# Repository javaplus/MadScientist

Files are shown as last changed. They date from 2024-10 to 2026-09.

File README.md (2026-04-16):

# Mad Scientist Lab V2.0 Sharks on Mars!

Fun learning with Electronics and Raspberry Pi Pico

This is the V2.0 of the Mad Scientist lab.  The original shark with laser game and more gentle introduction to electronics and the Pico can be found here: https://github.com/javaplus/PicoProjects

## The Grab

 Using Raspberry Pi Pico microcontrollers, Python, electric motors, 3D printed parts, and your ingenuity, you will construct a rover ready to conquer Mars! This vehicle will be capable of traversing rough surfaces like those of the red planet and will be programmable to handle out of this world challenges. Remember those mechanical sharks with freakin' lasers on their heads? Well HONEY WE BLEW UP THE SHARKS and will be using those shark parts to transform these rovers into the ULTIMATE MAD SCIENTIST vehicles to fend off any threats you may encounter in this extra-planetary conquest.
Once you've built your functioning rover in our lab, if you choose, you will have the opportunity to battle test your vehicle against other rovers to see whose design reigns supreme! Join us in this epic quest and learn to meld software and hardware together to accomplish our goal of bringing Sharks to Mars!

## Description

This is a tutorial for building a Shark Rover.  A Shark Rover is just like it sounds... a mix between a shark and a Mars-like rover.  

Nearly all the plastic parts are 3D printed and the brain is a Raspberry Pi Pico.  You will assemble the plastic bits and install the Pico, the motors, wires, and other electronics to make a functioning autonomous rover.
We will use Python as the programming language for the Pico microcontroller, but all code will be provided.

# Prepare Pico

To prepare the Pico, you need to flash it to support MicroPython.
Here are the instructions to [flash the Pico for MicroPython](/lessons/firmware.md).

# Getting Started

If you want to jump straight into building the Shark Rover, jump to the [Assembly](#Assembly) section.  If you want to take a slower approach and learn about each component, check out our [Lessons](#Lessons).

### 🚀 One-Day Event?

If you're building a rover for a one-day event with mixed/pre-assembled kits, start here: [Hackathon Build Notes](UA_hack_special_notes.md) — quick, scannable instructions designed for event participants.

# Lessons

The links in this section are to labs which walk you through working with the various components that will ultimately make up your rover. These labs will give you a better understanding of the individual parts and code that go into making the rover work.  However, these lessons do not actually get into building the rover, but are just for learning how the components work.  They are hands-on labs that actually have you working with the electronics and code, but do not include assembly of the rover.  The assembly is in its own section.  So, if you don't care to learn how the individual components work and want to skip straight to building the rover, then skip this section and go straight to [Assembly](#assembly) below.

[Blink Demo](/lessons/blink.md)  
[Simple LED](/lessons/Led.md)  
[LED PWM](/lessons/led_pwm.md)  
[RGB LED](/lessons/RGBled.md)  
[Working with Electric Motors](/lessons/SimpleMotor.md)  
[Motor Controller](/lessons/MotorController.md)  

# Assembly

[Pico Plate](/lessons/assembly/plate.md)  
[Chassis Motors](/lessons/assembly/chassis.md)  
[Wheels and Tracks](/lessons/assembly/wheels.md)  
[Power Components](/lessons/assembly/power.md)  
[Pico and Chassis Together](/lessons/assembly/plate_chassis.md)  
[Tail Tip/Photoresistor](/lessons/assembly/tail.md)  
[Tail Connection](/lessons/assembly/tail_chassis.md)  
[Head, RGB Leds, and adding the cap!](/lessons/assembly/head.md)  

# Install the Code

[Install the Code](/lessons/assembly/code_install.md)

# Customize the Code

[Custom Game Modes](/lessons/game_mode_coding.md)

# BlueTooth Remote

[Mad Scientist App](https://github.com/javaplus/mad_scientist_app)

---

## 🦈 Wiring Reference

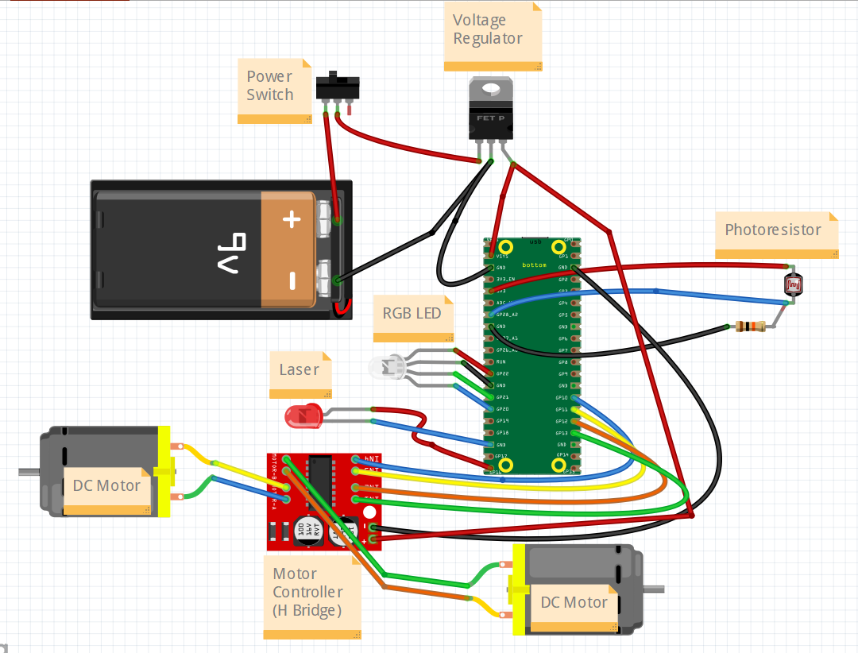
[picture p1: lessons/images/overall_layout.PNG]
Overall Wiring Diagram


**Use the image above for the main layout!**

> ⚠️ **One Addition (The Buzzer)**  
> The diagram is missing the buzzer, which we added later.  
> **Signal:** Connect to `GP15` (Right next to the Laser on `GP16`)  
> **Ground:** Connect to any `GND`

**Summary of Pins:**
- **Motors:** `GP10`, `GP11`, `GP12`, `GP13`
- **Buzzer:** `GP15`
- **Laser:** `GP16`
- **RGB Eyes:** `GP20` (Blue), `GP21` (Green), `GP22` (Red)

See [head wiring details](/lessons/assembly/rgb.md) for head wiring details.

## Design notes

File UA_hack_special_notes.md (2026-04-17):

# 🧪 Mad Scientist — Event Build Notes

This guide is designed to help you get your kit running quickly and safely. Because these kits are shared and reused, the most important rule is: **Build smart, not permanent.**

---

## 🛑 The Golden Rules (Read This First!)
To ensure these kits work for the next person, follow these rules strictly:
* **No Permanent Changes:** Never cut wires, solder, glue, drill, or sand any parts. 
* **Hands Off the Repairs:** If a part looks broken, frayed, or won't fit, **stop and ask a facilitator.** Do not attempt your own repairs.
* **The "Reversible" Rule:** If you can’t undo what you just did in 10 seconds, you’re doing it wrong.
---

## 🔌 Wiring & Connections
The wiring diagram is the final authority. If a tutorial says one thing but the diagram says another, **follow the diagram.**

* **Wiring Diagram:** [View Layout Image](lessons/images/overall_layout.PNG)
* **Pin Reference:** See the "Wiring Reference" in the [README.md](README.md#-wiring-reference).
* **Pro Tip:** If a connector doesn't slide in easily, check the alignment. **Never force a plug.**

---

## 🛠 Troubleshooting (Quick Fixes)

| Issue | Check This First |
| :--- | :--- |
| **No Power** | Check battery orientation and the physical power switch. |
| **Motor Swapped** | If the bot moves backward, ask a facilitator to run a "Motor Direction Test." |
| **Wrong LED Colors** | Your RGB harness might be upside down. Check the [RGB Guide](lessons/assembly/rgb.md). |
| **Smoke or Smell** | **Switch off power immediately** and notify a facilitator. |

---

## 🚀 Final Assembly
Once your electronics are tested and working:
1.  **Mount the Head:** Align the head unit with the chassis. It should slide or snap into place without force.
2.  **Secure the Cap:** Install the final top piece (the "Cap"). If unsure which piece this is, ask a facilitator.
3.  **Safety Check:** Ensure no wires are pinched or dragging on the wheels.

---

## 📚 Essential Links
* [Master Wiring Diagram](lessons/images/overall_layout.PNG)
* [Firmware & Code Install](lessons/assembly/code_install.md)
* [Full Parts List](resources/PartsList.md)

> **⚠️ LASER SAFETY:** This kit contains a Laser. Never look directly into the beam or point it at anyone’s eyes. (Facilitator will confirm safety protocol before use).

## Assemble Your Shark!

Go To Assembly Instructions:
[Assembly](README.md#assembly)

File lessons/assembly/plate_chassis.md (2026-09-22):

# Add Plate on Chassis

### Parts
- Pico plate (with Pico and motor controller)
- Chassis

In this step, we will take the Pico plate with the Pico and motor controller and attach it to the chassis.  

### Connecting the Motors

Before we can put the plate down on the chassis, we need to connect the motors to the motor controllers pins that stick out below the plate.  Position the chassis so that the hitch is facing towards you which means the power switch also is closest to you.  Then position the pico plate with the motor controller at the opposite side of the chassis.
See below picture for proper orientation.   

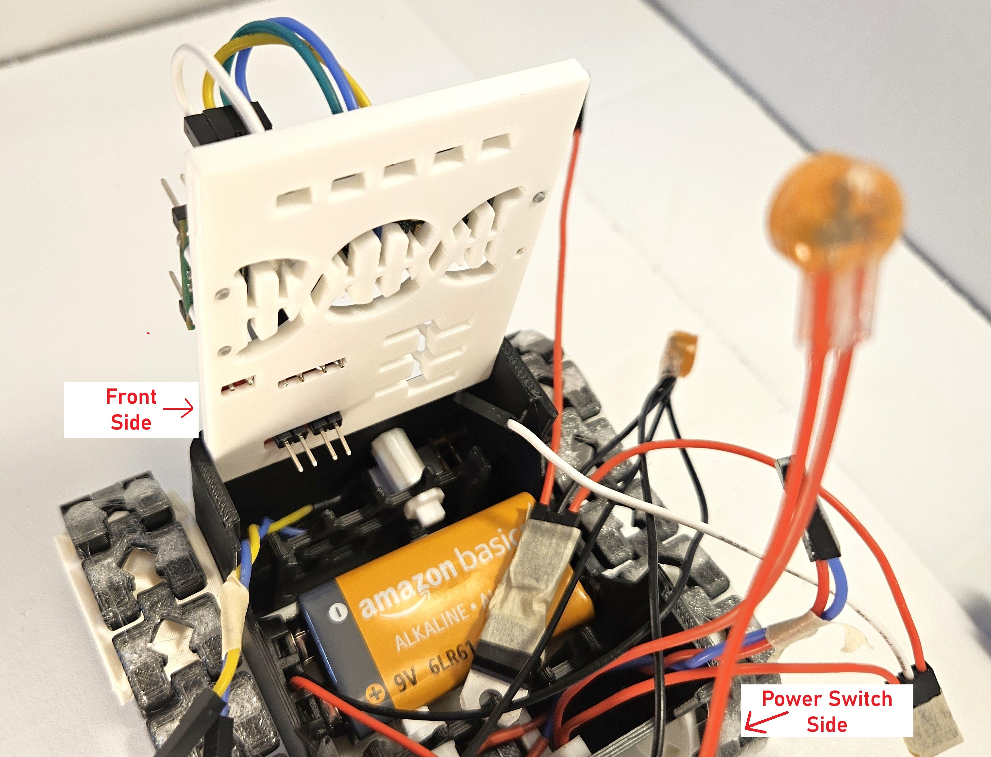
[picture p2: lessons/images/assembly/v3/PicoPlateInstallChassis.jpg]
Pico Plate bottom view


Now you will connect the motor wires to the motor controller pins that stick down through the pico plate. Connect the front motor to the `motor A` pins on the motor controller. The ``motor A`` pins are the first two pins on the left in the picture above. 

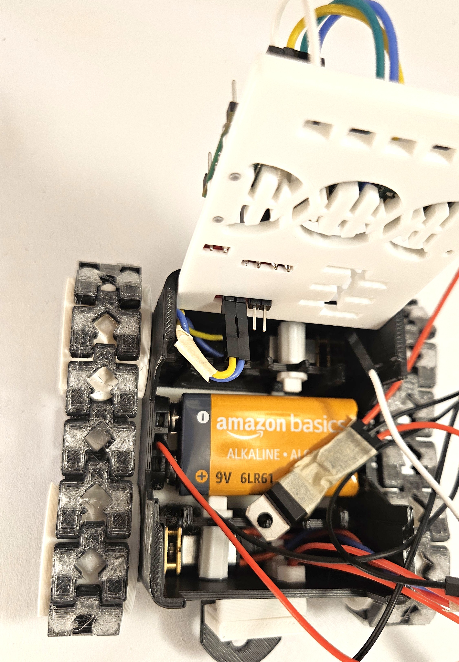
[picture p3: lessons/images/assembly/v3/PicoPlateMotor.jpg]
Pico Plate Motor A pins connected


 Connect the rear motor to the `motor B` pins.  Run the wires for the rear motor over the battery. You don't have to worry about the color of the wire and which pin it goes to.  As long as the front motor wires are connected to the `motor A` pins and the rear motor is connected to `motor B` pins, then which wire connects to which pin doesn't matter.   The reason it doesn't matter is because the motor controller can send power in both directions to a motor and therefore we can control in the code which way to send the power to get the motors to spin in the direction we want.

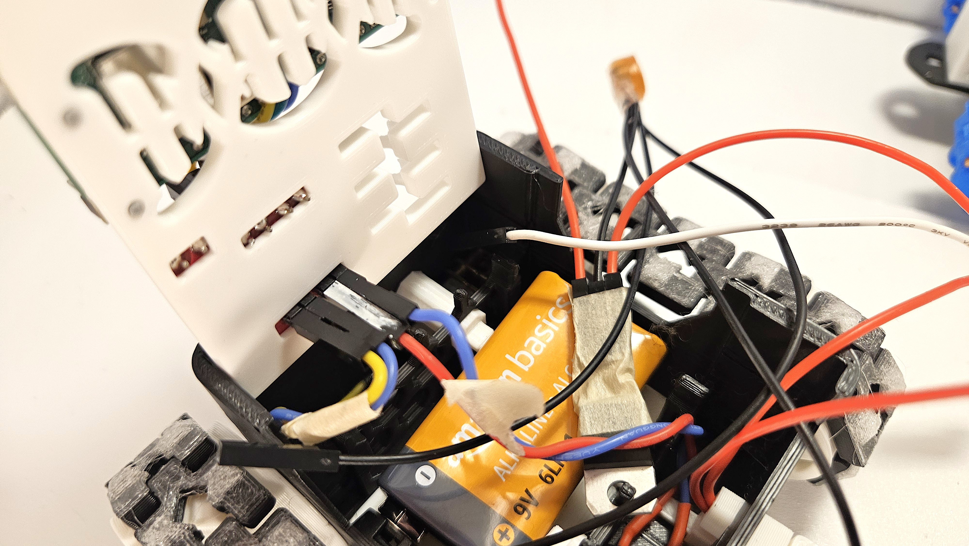
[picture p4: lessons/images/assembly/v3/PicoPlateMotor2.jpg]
Pico Plate Motor B pins connected


### Running the Power Wires

Now we need to route all the unconnected wires from the power up through the Pico Plate.  So, you should have 2 black ground wires and 2 positive wires(one red and one white).  Be sure to know which wire is coming straight from the 3 way connector and which is coming from the Voltage Regulator.  The one coming from the 3 way connector is carrying 9volts and could damage the Pico if we accidentally plugged it in there.  In our picture the white wire is carrying the 9volts and will go to the motor controller eventually.  For now, just run all 4 wires through the slots in the bottom right of the Pico Plate. Their position in the slots doesn't matter, just have them all poke through to the other side of the Pico plate.

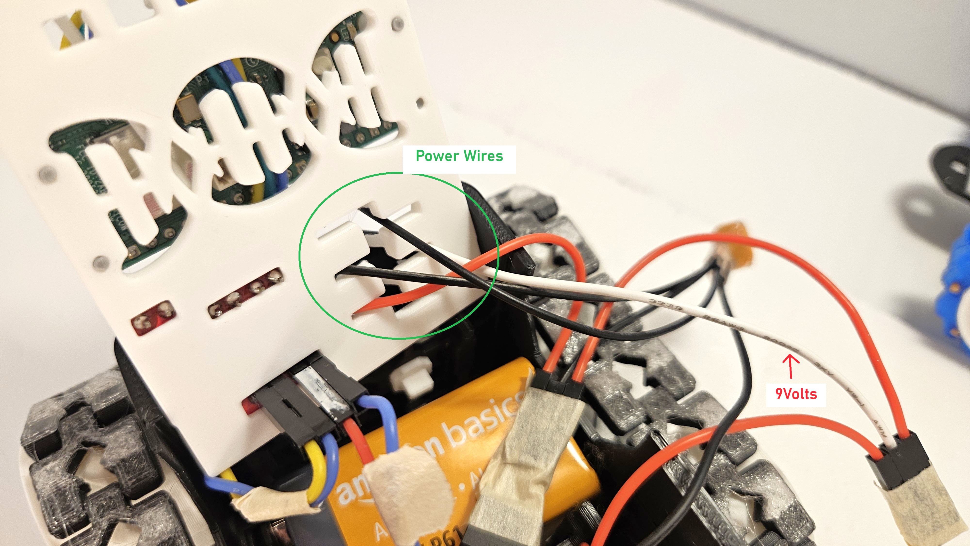
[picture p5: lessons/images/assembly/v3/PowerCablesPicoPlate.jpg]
Power Cables Through Pico Plate


With the 4 power wires through the Pico plate, you can set plate on top of the chassis. Don't worry about snapping the Pico Plate in place. At this point, just let the Pico Plate rest on top of the chassis.

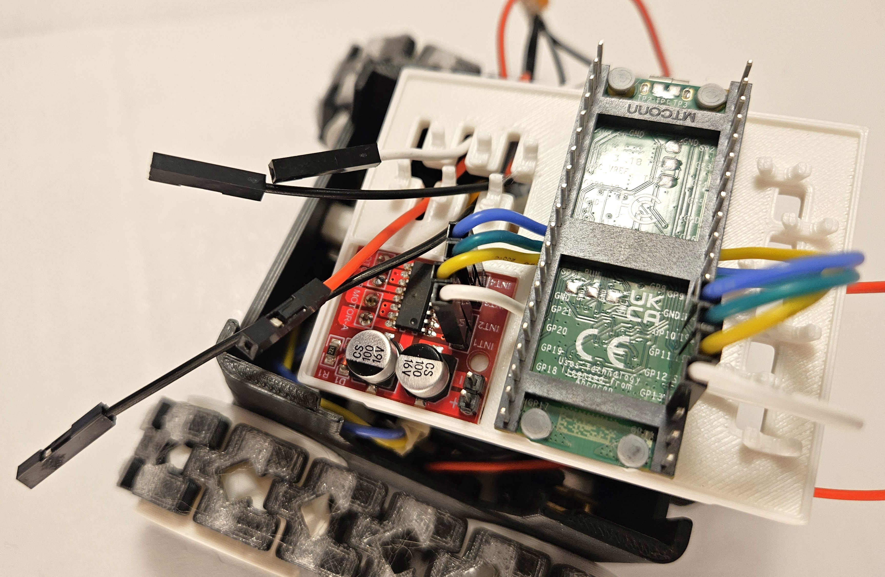
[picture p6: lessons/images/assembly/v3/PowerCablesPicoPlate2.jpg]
Power Cables Through Pico Plate Top View


Now we will try to push the Pico Plate into is final recessed position on the chassis.  To do this, start by positioning the Pico Plate inside the top of the chassis.

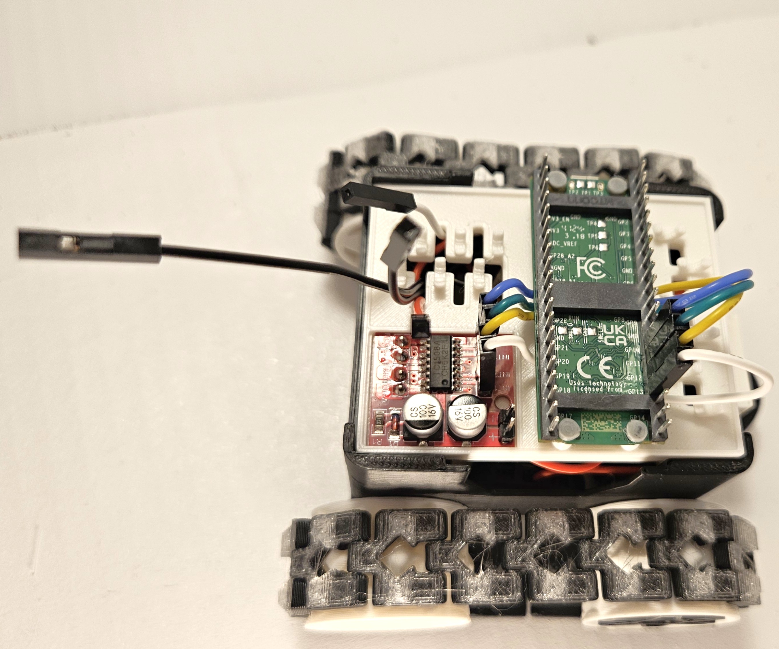
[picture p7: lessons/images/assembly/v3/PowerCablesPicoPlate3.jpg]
Pico Plate On Chassis


Your goal now is to carefully push the plate down onto the chassis. Make sure that the wires aren't disconnected or pinched between the plate and chassis. You may need to pull up on the ends of the power wires to bring slack up above the Pico Plate.  Continue to gently push the Pico plate down onto the chassis while keeping the wires from getting pinched. The plate should sit flush with the cutout in the front and rear of the chassis.

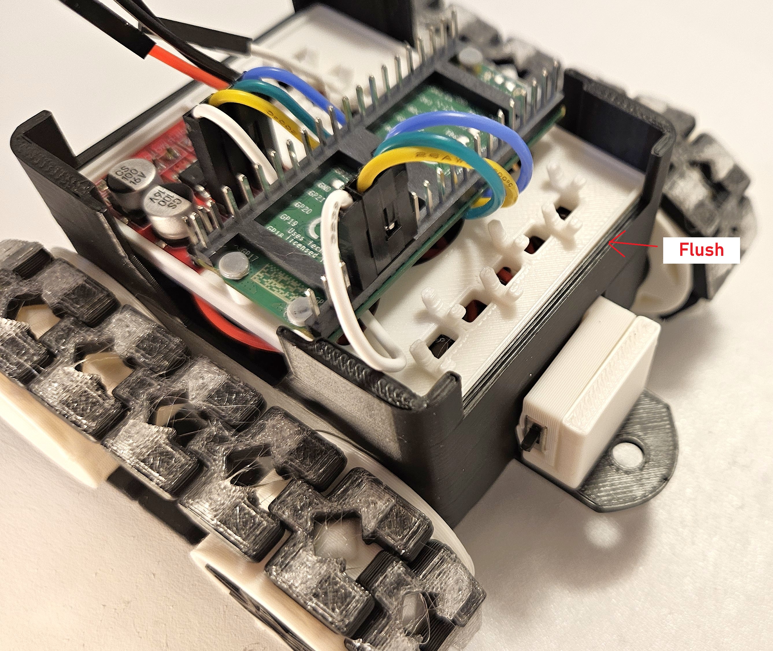
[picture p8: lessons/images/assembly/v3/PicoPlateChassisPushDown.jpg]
Pico Plate on Chassis Flush back
  

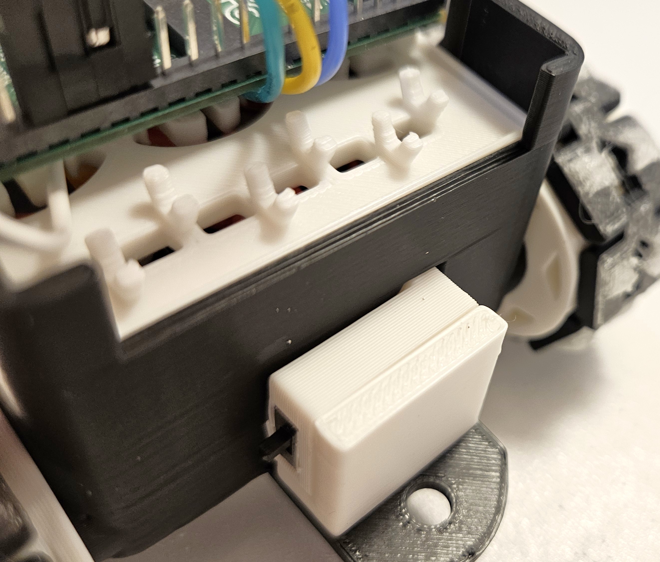
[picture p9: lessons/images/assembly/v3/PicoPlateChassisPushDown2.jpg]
Pico Plate on Chassis Flush back 2
  

Ensure the Pico is pushed down and flush with the front and back edges of the chassis.  You may have to reposition the wires underneath a few times and tuck them down in crevices by the motors to get it to fit flush.

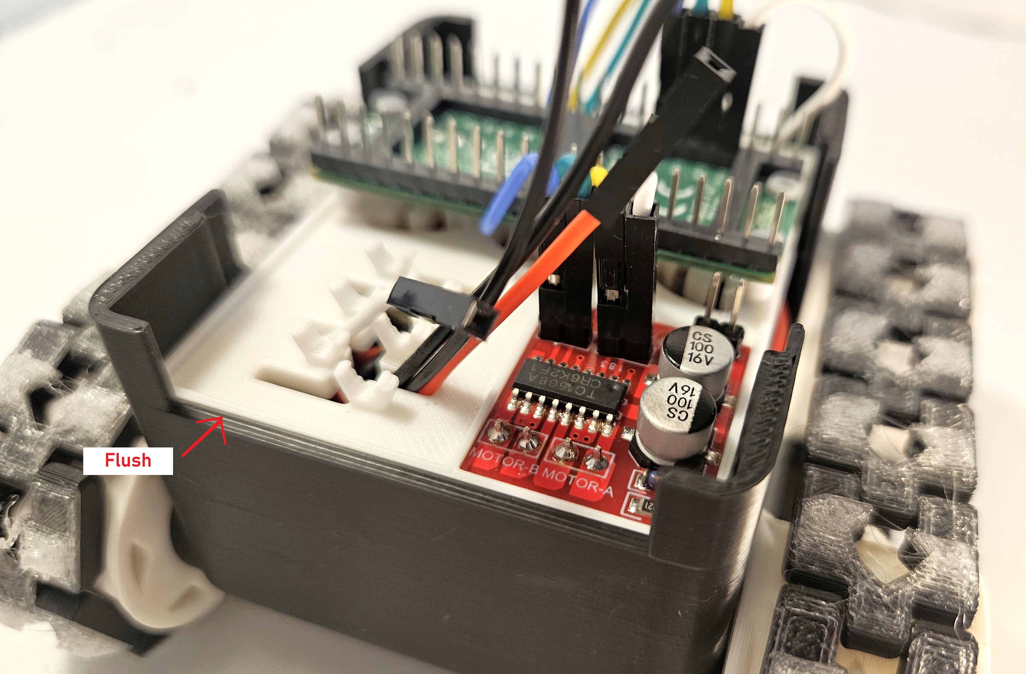
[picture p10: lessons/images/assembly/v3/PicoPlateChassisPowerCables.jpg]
Pico Plate on Chassis Flush Front


Now it's time to connect the power cables from the voltage regulator.  Connect either of the ground (black) wires to the (-) pin on the motor controller and connect the 9Volt positive wire (should be white) to the (+) pin on the motor controller.  The negative/ground pin is the one 

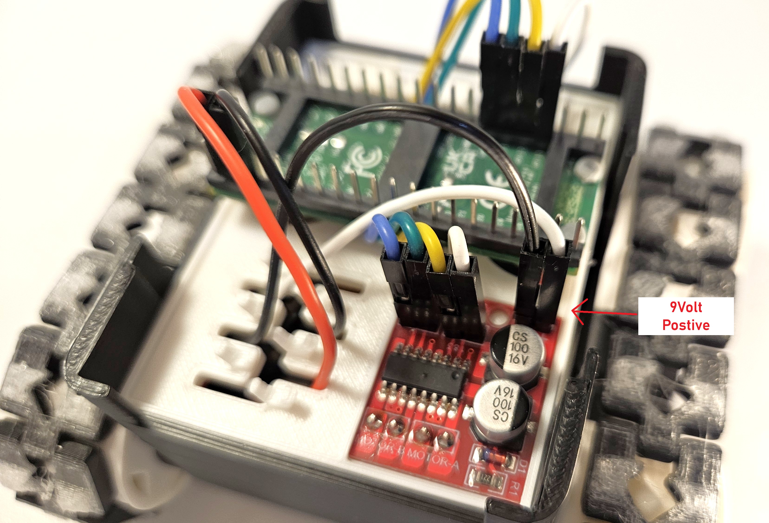
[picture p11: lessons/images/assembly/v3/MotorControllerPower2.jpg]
Motor Controller Power Wires


Now we need to connect the power to the Pico. 
Take the positive wire coming from the voltage regulator that should carry our 5 volts the Pico's VSYS pin (left side, second down from the ).  The other ground wire (black) connects right beside the VSYS pin into a GND(ground) pin on the Pico.  See the picture below and be sure to notice there is one single empty pin to the left of the positive wire and your red wire is connected to the second pin from the left in the picture below. There is always ground 3 pins in from any side on the Pico.

Here's a pinout diagram if you want to use it instead of the pictures:  
<details><summary> Click here to hide/show Pico Pin Out.</summary> 
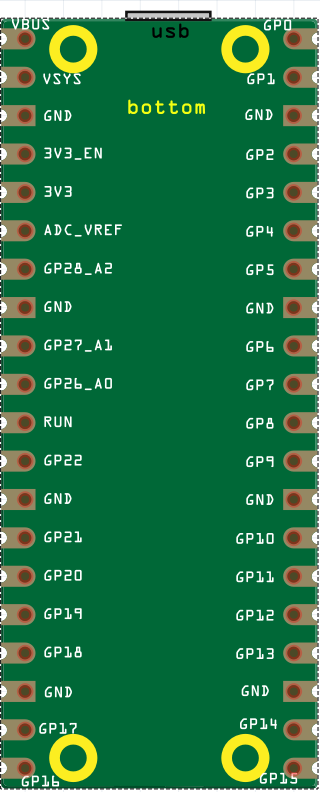
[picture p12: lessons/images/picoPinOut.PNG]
 
</details>

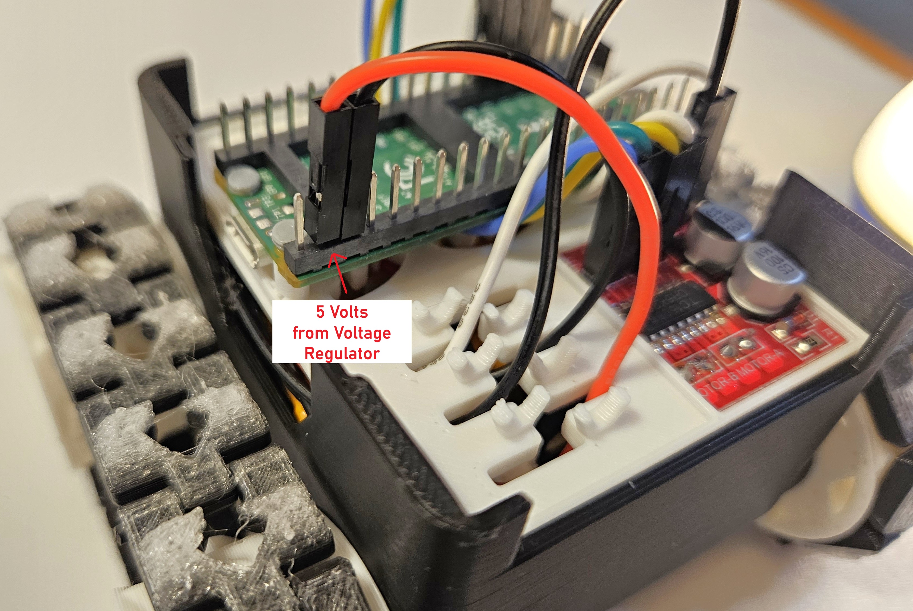
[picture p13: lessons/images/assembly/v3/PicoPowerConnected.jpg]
Pico Power Wires


The ground/black wire goes to a ground pin on the Pico.  We recommend the ground pin right next to the VSYS.  That is 3 pins down from the top left in the picture.

### Test the Motors

TODO: Add instructions to test the motors via a simple program on they load on the Pico.  Similar to the motor controller lesson. Preferably the same code.

### Install Rover Code

Congratulations! You are super close to having a mobile rover!

Actually, if you already have your wheels and tracks installed, you may want to go ahead and install the code and test out what you have built.

You should be able to install the code and use the mobile app to test the basic drivability of your rover.

- [Install Shark Code](/lessons/assembly/code_install.md)  
- [Mobile app](https://github.com/javaplus/mad_scientist_app/blob/main/README.md)

[back](https://github.com/javaplus/MadScientist/blob/main/lessons/assembly/power.md)                

[next](https://github.com/javaplus/MadScientist/blob/main/lessons/assembly/tail.md)

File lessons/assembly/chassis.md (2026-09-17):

# Chassis Assembly

### Parts

- Chassis
- 2 motors
- 2 hex plugs

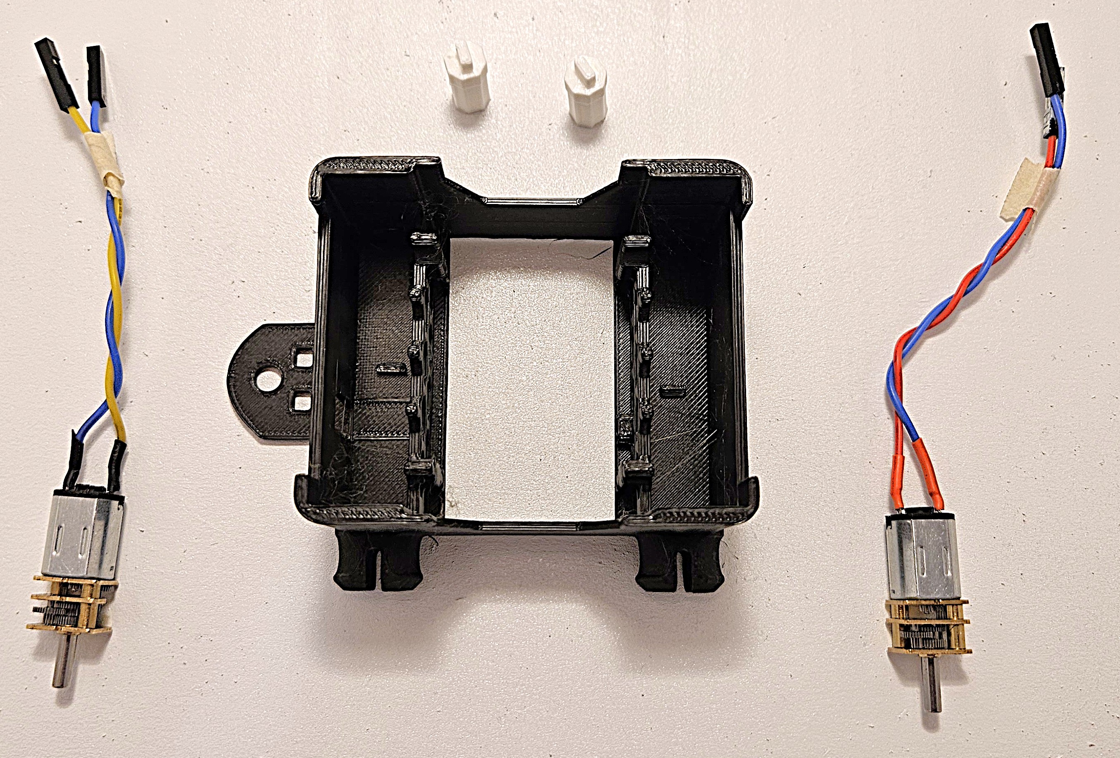
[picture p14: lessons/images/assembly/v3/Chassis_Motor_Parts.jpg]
Chassis and Motors Not Installed


### Remove tabs

There may be two tabs attached to the inside bottom of your chassis.  If they are on your chassis, remove them.  They should easily bend and snap off with little effort. They are not needed. 

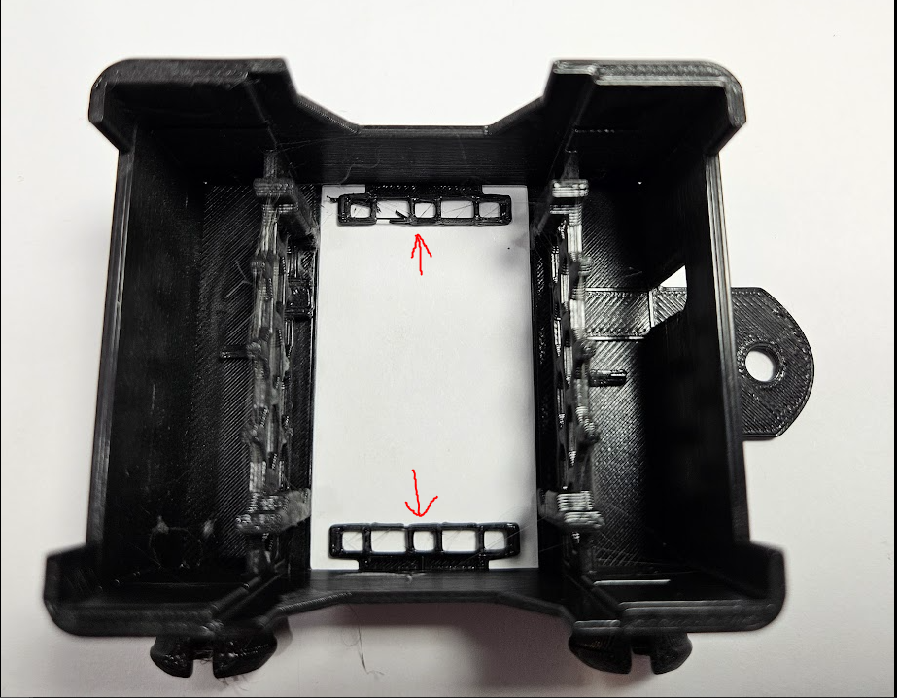
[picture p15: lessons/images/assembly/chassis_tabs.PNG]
Remove Tabs


### Add Motors

Orient the chassis with the "hitch" to the right (see picture below).
The motors have a flat top and bottom and rounded sides.  When inserting the motors, a flat side should rest against the bottom of the chassis so that the wires are horizontal.
Insert one motor into the top left and one into the bottom right.  Make sure the shaft extends out of the chassis as much as possible.  
There is a small tab on the floor of the chassis behind each motor.  Make sure the motor is pushed in so that the tab is behind the motor.

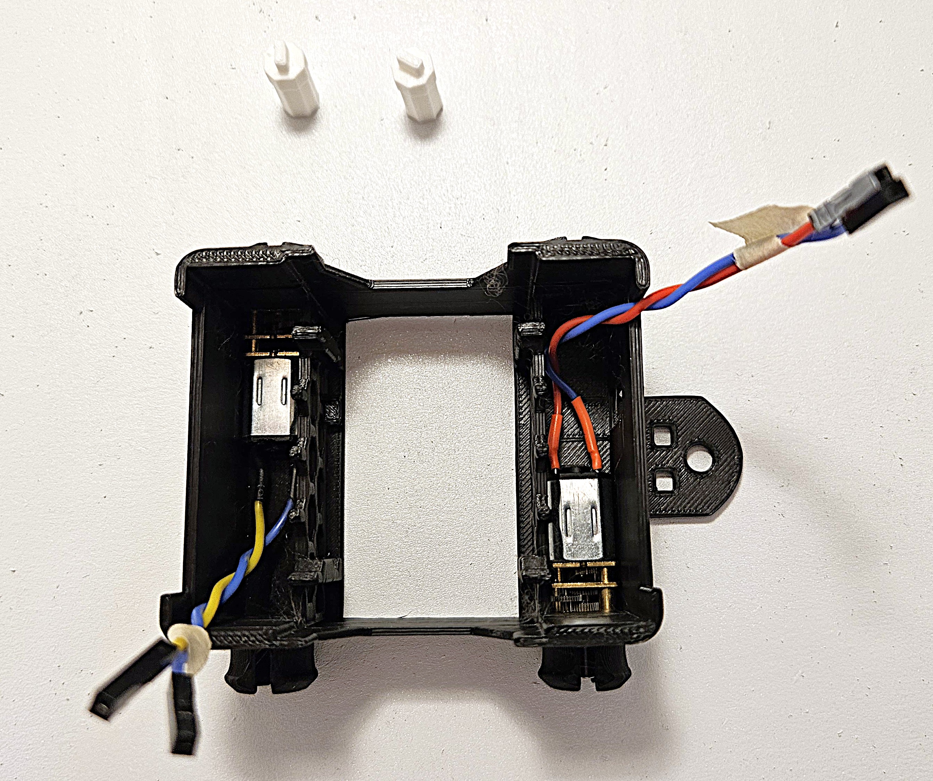
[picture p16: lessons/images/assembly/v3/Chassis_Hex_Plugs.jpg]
Chassis and Motors Installed


If the motor is installed properly the shaft or axle should extend out almost as far as the wheel hubs on the chassis.

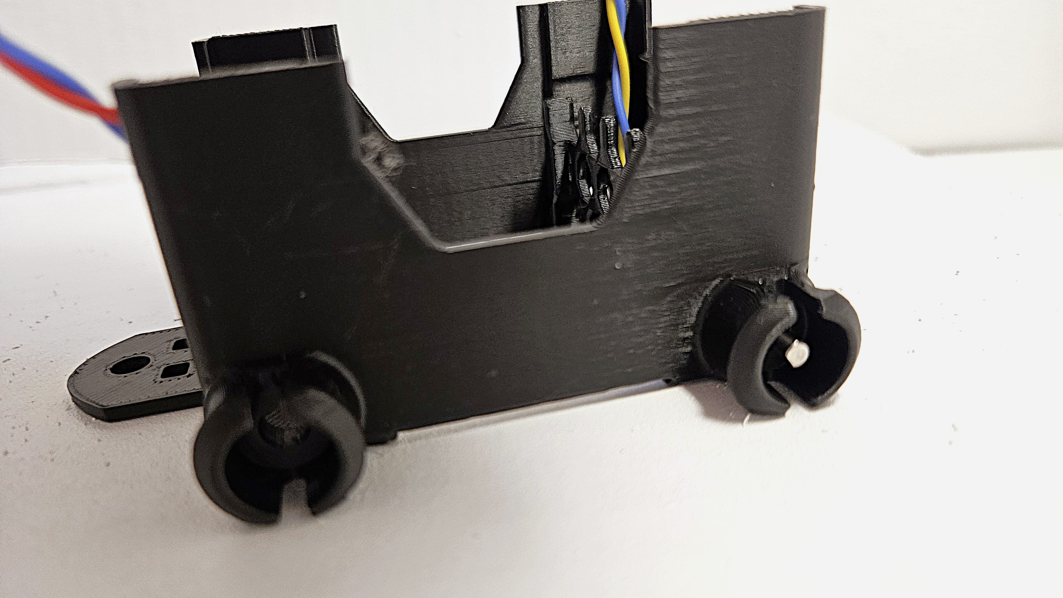
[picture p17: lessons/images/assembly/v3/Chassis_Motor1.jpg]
Axle Sticking Through Side Angle


Notice that the axle should protrude almost to the edge of the wheel hub on the chassis if installed correctly.

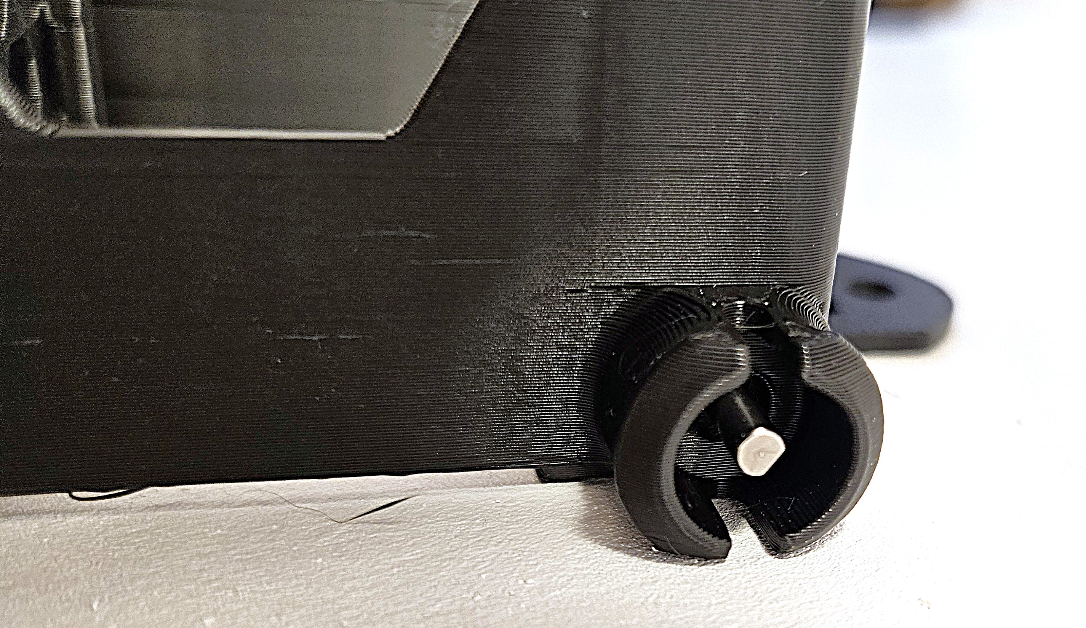
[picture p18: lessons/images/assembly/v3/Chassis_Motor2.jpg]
Axle Sticking Through Close Up


With the motors installed, take your hex plugs and slide them into the hex hole above the back of each motor.  Be sure to orient the hex plugs so they match the shape of the hole in the chassis and the tab on the end of the hex plug is horizontal.  Push the hex plug into place so that the fatter end of the hex plug is wedged into the chassis. 

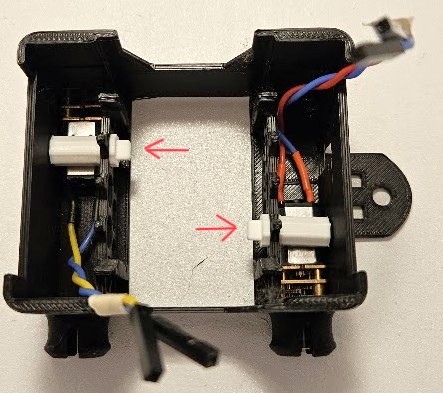
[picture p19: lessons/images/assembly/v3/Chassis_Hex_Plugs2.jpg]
Hex Plugs Installed in Chassis


To snap them into place, it's recommended to use a pinching motion with your thumbs on the hex plug and your fingers on the outside of the lattice structure they go through.  The picture below shows using one hand, but two hands are better.

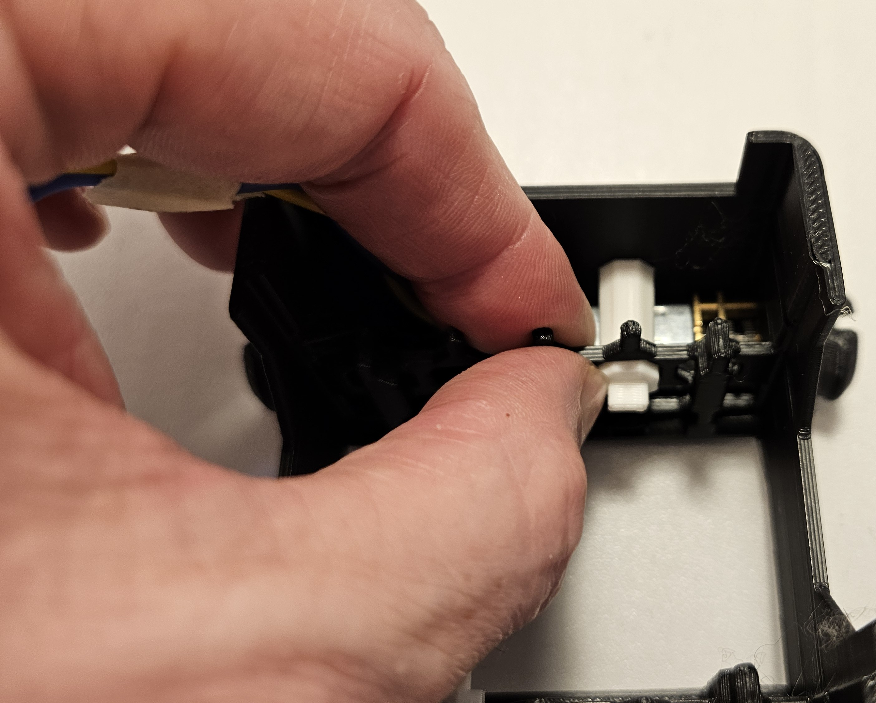
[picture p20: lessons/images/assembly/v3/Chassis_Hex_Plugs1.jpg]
Close up of pinching Hex Plugs into Chassis


 If the hex plugs do not fit super snugly, it's ok.  The hex plugs just help keep the motors in position while you put on the wheels and transmission pieces.  The hex plugs are optional and if they are not fitting well you can leave them out.

Once the motors are securely in place you are done with this step!

[back](https://github.com/javaplus/MadScientist/blob/main/lessons/assembly/plate.md)

[next](https://github.com/javaplus/MadScientist/blob/main/lessons/assembly/wheels.md)

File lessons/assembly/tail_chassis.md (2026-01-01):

# Attaching the Tail

### Parts
- Tail with Tail Tip and Photoresistor installed
- Plastic power switch
- Tail connector

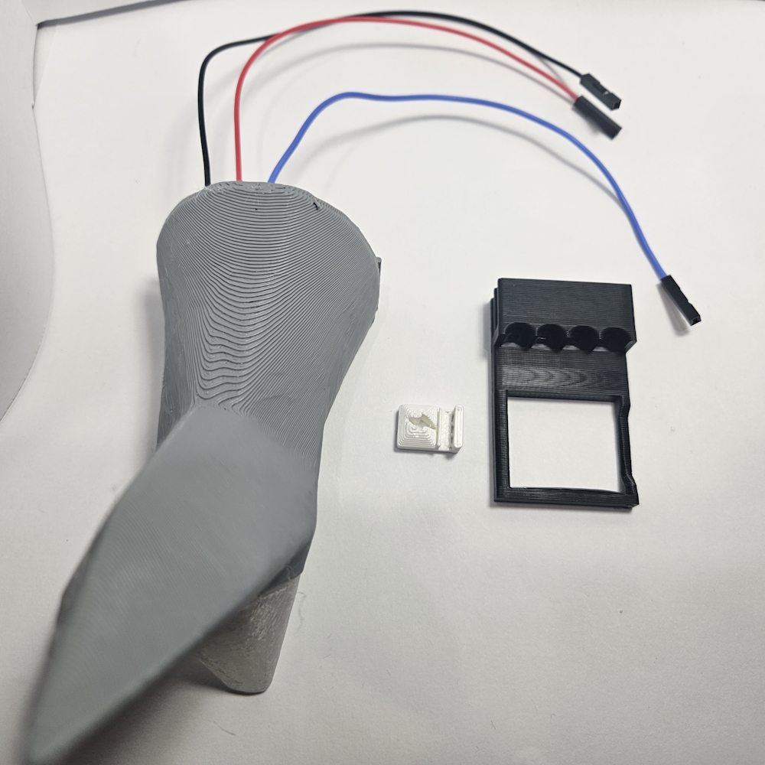
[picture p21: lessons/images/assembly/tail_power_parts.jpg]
Tail and Power Switch Parts


### Add Power Switch

Notice that there are 3 small notches in the bottom of the 3D printed power switch as seen in the picture below.

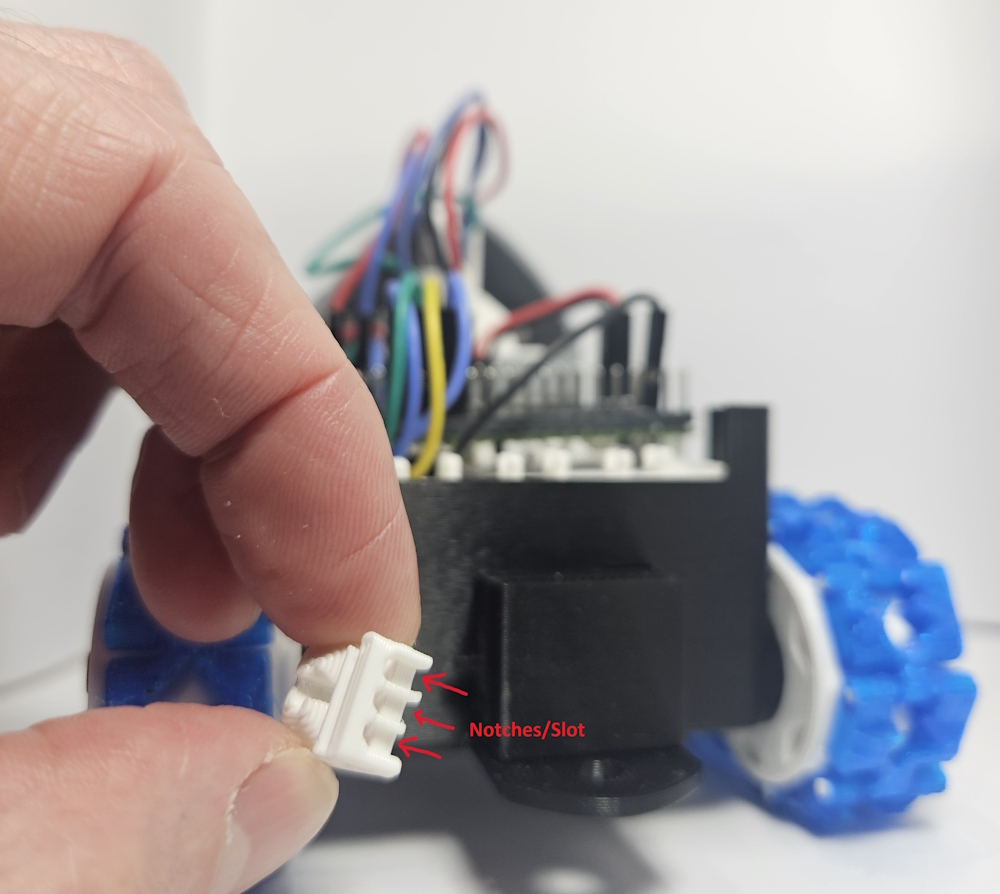
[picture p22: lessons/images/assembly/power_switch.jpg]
Power Switch Notches
  

Make sure the physical power switch which you wired earlier is in the fully down position before adding the 3D printed power switch on top of it.
Hold your power switch in the orientation as seen in the picture above so you can see the slots, then place it over the physical power switch on the back of the chassis.
Make sure to put the power switch into the top most slot/notch of the 3D printed power switch.  It's easier to do this if you tip the back of the rover up.

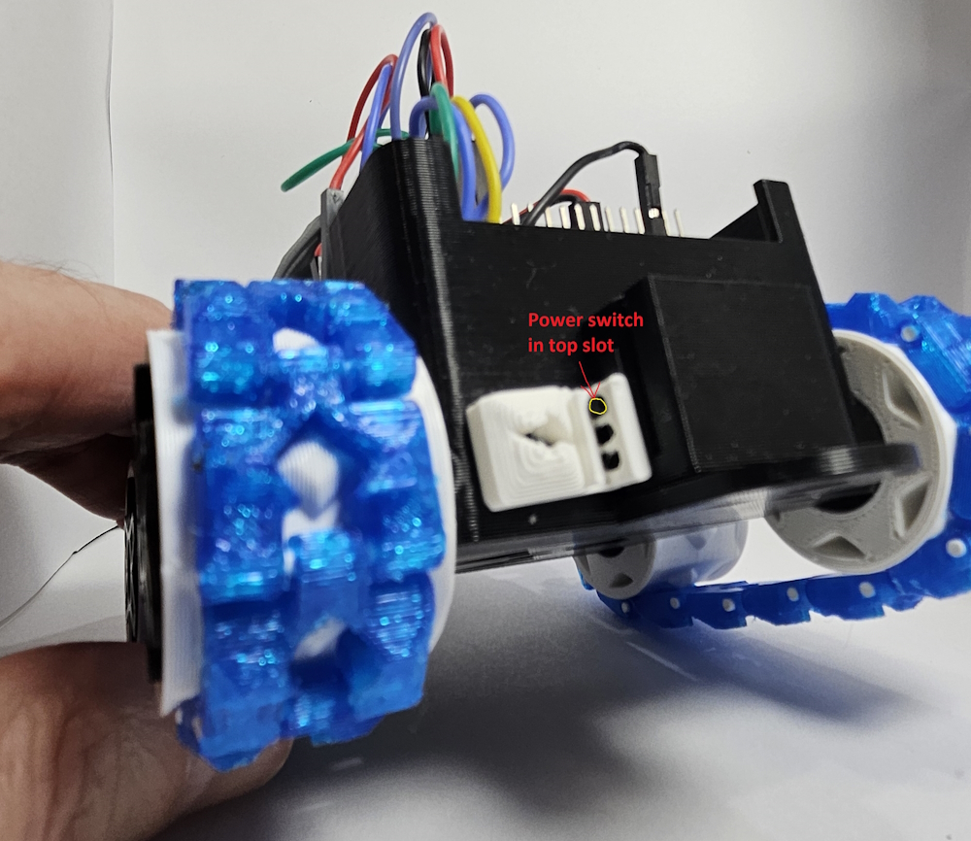
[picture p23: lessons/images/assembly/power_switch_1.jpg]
Power Switch on Chassis
  

Zoomed View of Switch:
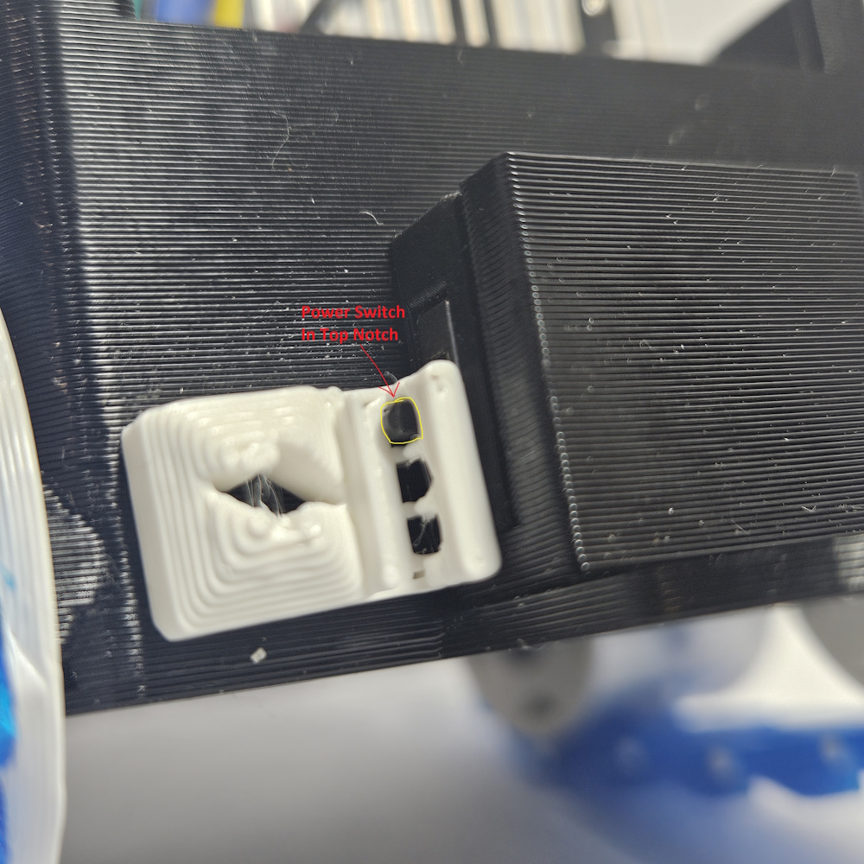
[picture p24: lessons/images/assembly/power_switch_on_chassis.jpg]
Power Switch on Chassis


### Tail Connector

Now take the tail connector piece and slide the square frame over the power box that contains the power switch.  Note that the 3 slots go up towards the top and the first two slots should go over the chassis.  The thinner vertical part of the frame goes in the vertical slot of the power switch.  See the pictures below for correct orientation and installation.

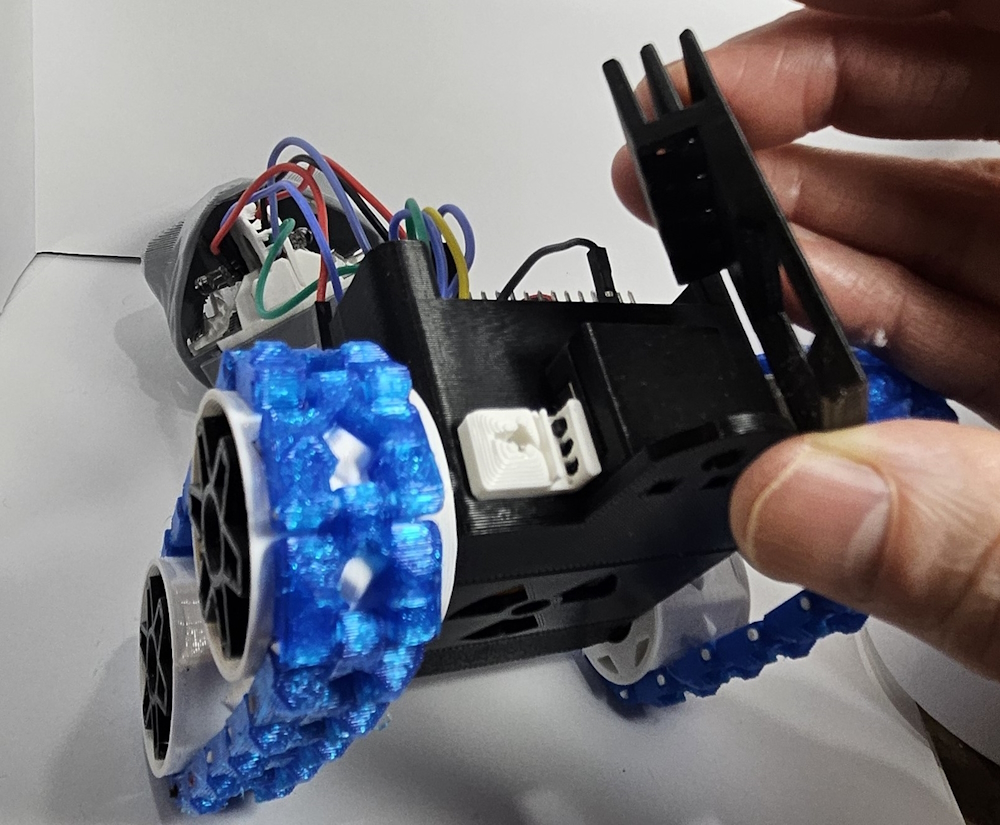
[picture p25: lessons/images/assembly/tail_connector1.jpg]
Tail Connector


Tail Connector 2

Tail Connector 3

Hold the tail connector you just installed in place and see if you can actuate the power switch up and down.  It should slide relatively easily with just a little resistance.  Be careful not to use too much force.

### Connect the tail

Now the tail can be slid into the slots of the tail connector.  The leading slot of the tail goes into the leading slot of the tail connector.  

Tail Attaching

Tail Connected

Tail Connected

Once tail is slid correctly into the tail connector slots, the tail should lock the tail connector to the chassis and hold the extended power switch in place.

### Wire the Tail

Now we are going to connect the photoresistor in the tail to the Pico.  If you have a lot of excess wire sticking out of the tail, you may want to loop them into a really loose knot.

Tail Wires

Connect the red wire to the `3V3` pin on the Pico which is 3 pins down from the `VSYS` power pin the voltage regulator is connected to.
Connect the blue or yellow wire from the photoresistor to the `GP28_A2` pin which is 2 pins below the `3V3` pin.

Now we simply connect the black wire to a GND pin on the Pico.  We are using the AGND pin on the Pico which is directly below the `GP28_A2` pin. 

NOTE: The 3 photoresistor wires are marked with yellow lines in the pictures below:

Tail Wires connected

Tail Wires connected

Your tail is now attached and ready for some swimming!

[back](https://github.com/javaplus/MadScientist/blob/main/lessons/assembly/tail.md)

[next](https://github.com/javaplus/MadScientist/blob/main/lessons/assembly/head.md)

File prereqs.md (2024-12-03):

## Prerequisites

You need a simple Python editor called Thonny which allows you write code on your laptop and execute it on the Pico via a USB cable. USB cables will be provided just make sure you have a laptop with Thonny installed and an available USB jack on your laptop.  
We will have a few USB C to USB A adapters for those with only tiny ports. We will not have Mac dongles so make sure you have a way to connect a USB A cable into your laptop. 

Please download and install the latest version(4.x or higher) of Thonny.  
[Download Thonny](https://thonny.org/) 

For these labs, you do NOT have to be a Python expert.  You can probably get by fine without having ever done Python programming before.  
However, some general programming knowledge is required. As long as you are comfortable with basic programming constructs(IF/ELSE statements, 
For/While loops, etc...) in other languagues we will have enough of the code for you to figure out the Python bits.
If you want to get a little familar with Python before coming you can check out this free tutorial get comfortable with Python. 
We will have code samples and links to reference materials if you just need to see how to do "normal" programming things in Python.
[Python Tutorial](https://www.learnpython.org/)

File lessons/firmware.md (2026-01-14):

# Prepare Pico for MicroPython

In order to use Python on a new Pico, you need to update the firmware to enable MicroPython.

I've found the easiest way to do this is to use Thonny.

[Download Thonny](https://thonny.org/)

Open Thonny and then get ready to connect the Pico via a micro USB cable.  Hold the "BOOTSEL" button on top of the Pico as you plug the Pico in.

Pico WH Bootsel button

You may hear your computer detect a new device and maybe even open a file explorer like View.  If so, close this and just go back to Thonny.

In Thonny, go to the `Tools` menu and choose `Options`:

Thonny Options

In the Thonny `Options` screen, select `MicroPython (Raspberry Pi Pico)` as the interpreter in the dropdown at the top. 

Next, click the `Install or update MicroPython` link at the bottom right:

Thonny Options Popup

In the `Install or update MicroPython` popup window, choose the "RPI-***" device in the `Target volume` drop down.

The `variant` should be `Pico W / Pico WH`. Be sure to pick `Pico W` and not the normal `Pico` the `W` is important!

Thonny Firmware

Once the target volume and variant are set properly, click Install.

It may take a minute or two to install and your computer may detect a new device during this process.

When it's done, close the pop up windows in Thonny to get back to the main Thonny screen.

Now go to the very bottom right to select your MicroPython enabled device from the drop down.

Note: Your COM port number may be different.

Thonny Device

Once you've selected your device, you should see the Shell change to show the version of MicroPython installed on your Pico.

Thonny done   

NOTE: Your exact version of MicroPython may be slightly different than the screenshot above, but be sure you see `Raspberry Pi Pico W` in the output.  Again, the `W` is important!

### Operating System Qwirks

If you're running Thonny with Flatpak on Linux, you may need to add yourself to the `dialout` group:

1. `sudo usermod -aG disk,dialout $USER`

On some operating systems, like Fedora Atomic setups, you may need to allow the `dialup` group
be to assignable first:

1. `grep -E '^dialout:' /usr/lib/group | sudo tee -a /etc/group`
2. ensure it's added with `cat /etc/group | grep dialout`
3. now run `sudo usermod -aG disk,dialout $USER`

### Install picozero library

Go to this link and follow just the few steps to [install the picozero library.](https://picozero.readthedocs.io/en/latest/gettingstarted.html#install-picozero-from-pypi-in-thonny)

Now you should be good to go!!!

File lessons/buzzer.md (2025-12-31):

# Adding a Buzzer

Adding a buzzer to the Shark Rover allows it to communicate status updates, low battery warnings, or just play fun "disco" sounds.

## Parts Required

* **Passive Buzzer Module:** Ensure it is "Passive" (requires a PWM signal to generate tone), not "Active".
* **Jumper Wires:** Female-to-Female (or matching your header type).

## Wiring

Connect the buzzer to the Raspberry Pi Pico. We will use **GP15** for this example, located next to the Laser pin (GP16).

| Buzzer Pin | Pico Pin |
| :--- | :--- |
| **Signal / (+) / I/O** | **GP15** |
| **GND / (-) / Minus** | **GND** |
| **VCC** (If present) | **3.3V** |

> *Note: Simple 2-pin buzzers just need Signal and Ground. 3-pin modules may require VCC.*

---

## Technical Concept: How PWM Works

The Raspberry Pi Pico is a digital device, meaning it usually only sends "On" (3.3V) or "Off" (0V) signals. To make different sounds (or dim LEDs), we use **Pulse Width Modulation (PWM)**.

PWM Duty Cycle Diagram  
*Figure: PWM creates an analog-like signal by switching on and off rapidly.*

PWM turns the digital pin on and off extremely fast—thousands of times per second. This creates a "square wave" that the buzzer vibrates to, creating sound.

### 1. Frequency = Pitch
**Frequency** is how many times per second the wave repeats (measured in Hertz, Hz).
* **Low Frequency (e.g., 100 Hz):** The buzzer diaphragm vibrates slowly, creating a deep, low sound.
* **High Frequency (e.g., 2000 Hz):** The diaphragm vibrates quickly, creating a high-pitched beep.

### 2. Duty Cycle = Volume (and Power)
**Duty Cycle** is the percentage of time the signal is "High" (On) versus "Low" (Off) during one cycle.
* In MicroPython, this is set using a 16-bit integer, where **0** is 0% and **65535** is 100%.
* For a buzzer, a **50% duty cycle** (around 32768) is typically the loudest, as the diaphragm pushes and pulls equally.

---

## Software Installation

### 1. The Buzzer Library
The buzzer class is already available in the repository.
* **File Location:** `code/buzzer.py`

Ensure this file is uploaded to your Pico. This class uses `asyncio` for non-blocking beeps (so the shark can keep driving while beeping) but also includes standard blocking functions for complex sound patterns.

### 2. Integration into Main
To use the buzzer in your main rover code (`main.py`):

1.  **Import:** Import the `Buzzer` class from the `buzzer` file.
2.  **Initialize:** Create a variable (e.g., `shark_sound`) and initialize the `Buzzer` on **pin 15**.
3.  **Usage:**
    * **Startup Sound:** Call `buzzDisco()` to play a sequence on startup (note: this may block execution for a few seconds).
    * **Status Beep:** Call `buzzTimeNFreq(time, frequency)` for non-blocking beeps while driving.
    * **Warning Tone:** Call `buzzLow()` for a continuous hum, and `stop()` to silence it.

## Troubleshooting
* **No Sound:** Check that you are connected to the correct GPIO pin and Ground.
* **Clicking/Static:** Ensure you are using a **Passive** buzzer. Active buzzers (which generate their own tone) do not work well with PWM signals.
* **Volume:** Passive buzzers driven directly by the Pico GPIO are generally quiet. Ensure the sticker is removed from the top of the buzzer.

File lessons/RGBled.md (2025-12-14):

# RGB Leds

RGBLED

First, what does RGB mean? well it stands for red, green and blue. This will allow LED to turn multiple colors.  
The diagram below shows what each pin does when powered.

LEDdia

First plug in the RGB led into pico as shown in the picture below using four female to female wires. Note the orientation of the Pico in the picture is with the pins still up in the air.  
The black wire in the picture below connects to the longest pin, which is the ground  pin.  The pin on the edge next to it is connected to the red wire.  Again wire color doesn't really matter, but it does help you keep straight what is connected to what.  

LEDFritz

Now let's write some code to give the LED some color!

```python
from machine import Pin
import utime

red = Pin(22, Pin.OUT)

green = Pin(21, Pin.OUT)

blue = Pin(20, Pin.OUT)

def alt_colors (color, cooldown):
    color.value(1)
    utime.sleep_ms(cooldown)
    color.value(0)

while True:
    alt_colors(red, 1000)
    
    alt_colors(green, 1000)
    
    alt_colors(blue, 1000)
```
this code will give power to each pin one at a time, making the led flash the 3 primay colors!

Now lets have the led fade into different colors. In this code we will be using the library PMW(pulse width modulation)
  allowing us to change the values of the brightness/color.     
  
  [Learn more about PWM!](https://github.com/javaplus/MadScientist/blob/main/lessons/led_pwm.md)

Here we will make a function called alt_colors() passing in the different pins to cycle through different duty cycle values to control the brightness of the LED.

```python
from machine import Pin, PWM
from time import sleep

red = PWM(Pin(22))
red.freq(1000)

green = PWM(Pin(21))
green.freq(1000)

blue = PWM(Pin(20))
blue.freq(1000)

def alt_colors(color):
    
    for duty in range(0,65535,1):
        color.duty_u16(duty) # 65535 is max color brightness

    for duty in range(65535,0,-1):
        color.duty_u16(duty) # 65535 is max color brightness

while True:
    alt_colors(red)

    alt_colors(green)

    alt_colors(blue)
# you can change colors by alt_colors(red, green or blue)
```

Up to this point, we've only ever had power going to a single pin at a time and therefore only producing one of 3 colors: Red, Green, or Blue.

However, the power of the RGB LED is that it can produce any color you want by mixing Red, Green, and Blue.  You can control how much of each color based on the duty cycle of the appropriate pin.

Let's mix the colors now with some new code!  

```python
from machine import Pin, PWM
from time import sleep

red = PWM(Pin(22))
red.freq(1000)

green = PWM(Pin(21))
green.freq(1000)

blue = PWM(Pin(20))
blue.freq(1000)

# Function to turn completely off
def off():
    blue.duty_u16(0)
    red.duty_u16(0)
    green.duty_u16(0)
    
while True:
    # Full blue
    blue.duty_u16(65534) # 65534 is the max color brightness
    # Mix in half red
    red.duty_u16(35565)
    # this makes purple

    sleep(0.5)

    off()

    sleep(0.5)

    # a little blue
    blue.duty_u16(25545)
    # a lot of red
    red.duty_u16(65534)
    # this makes pink

    sleep(0.5)

    off()
    
    sleep(0.5)
```

You can change the duty value which is the brightness of the color.  
the max value is 65534 and 0 means off. get creative here mix all the colors  
or just two colors by using or changing (color).duty_u16(color value)

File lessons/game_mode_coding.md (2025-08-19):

# Programming New Game Modes

## Overview
Game modes really come down controlling what happens when you get hit, motor speed, what to do when you fire, and what sounds to make when.

## Base Class
To implement a new game mode, you need to create a new class that extends/implements the [`BaseGame` class](https://github.com/javaplus/MadScientist/blob/3be6801566cf3852717db674f972e4c576ec4078/code/basegame.py#L3).

```Python

from motor_class import MotorController

class BaseGame:
    # Constructor gets motor_controller and rgb
    def __init__(self, motor_controller, rgb, laser, buzzer):
        self.motor_controller = motor_controller
        self.rgb = rgb
        self.laser = laser
        self.buzzer = buzzer

    ## Implement Setup (initialize rgbs and motor status)
    def setup(self):
        pass

    ## implement on Hit.
    def onHit(self):
       pass
   
    ## implement on Fire.
    def onFire(self):
       pass

```

## Custom Game Class

When you extend this class you get the constructor by default which takes in the `motor_controller`, the `rgb`, buzzer, and the `laser`.

These are the 4 things with the current hardware you can control.

Here's an example of how to extend it with a simple implementation:

```Python
from basegame import BaseGame
from laser import Laser
from motor_class import MotorController

class BasicGame(BaseGame):

    ## Implement Setup
    def setup(self):
        # set color to green
        self.rgb.color = (0, 255, 0)
        self.laser.turnOn()

    ## implement on Hit.
    def onHit(self):
        print("Basic Game been hit!!")
        # Let's flash our eyes
        # go red
        self.rgb.color = (255, 0, 0)
        self.motor_controller.spin_lock()
        self.laser.turnOff()
    
```

Notice that there is no need to create a constructor when you implement the `BaseGame` class as you inherit its constructor.

This `BasicGame` class simply sets the color to green on setup.

The `onHit()` function simply changes the color to red and then causes the motor to do a `spin_lock`, which is basically just a forced spin for a certain amount of time.

## How the Game Class is used

The `setup()` function gets called as soon as the game mode is changed or initiated.
Currently, the game mode can change based on the command from the bluetooth remote app.
In [main.py](/code/main.py), the `execute_command()` function has an `if` block to set the game mode. The `initializeGame()` function takes in the game mode string to determine what game mode to use by calling the `setGameMode()` function (also in `main.py`) that will instantiate the appropriate game class and return it.  

Here is the `initializeGame()` function(NOTE: This is for informational purposes, you should not have to change this function for your own game class):

```Python
def initializeGame(gamemode):
    global hitevent
    global laser
    global buzzer
    global fireevent
    
    # reset HitEvent to remove previous subscribers
    hitevent.reset()
    fireevent.reset()
    
    # get the game
    game = setGameMode(gamemode, motor_controller, rgb, laser, buzzer)

    # setup game
    game.setup()

    ## Set the method to be called when hitevent fires!
    hitevent.subscribe(game.onHit)
    fireevent.subscribe(game.onFire)

```

Notice the `initializeGame()` function resets the game events. Currently there's only `hitevent` and `fireevent`.
It also then subscribes the game class returned by `setGameMode()` to the `hitevent` and `fireevent`.  This allows the game class's `onHit()` function to be called when there is a hit detected. And the `onFire()` function of your game class to be called with the fire button is pressed.

Let's look at the `setGameMode()` function now:

```Python

## to select the game mode
def setGameMode(gamemode, motor_controller, rgb, laser, buzzer):
        if gamemode == "virus":
            print("Virus mode")
            return VirusGame(motor_controller, rgb, laser, buzzer)
        elif gamemode == "disco":
            print("Disco mode")
            return DiscoGame(motor_controller, rgb, laser, buzzer)
        elif gamemode == "hungry":
            print("Disco mode")
            # Return Hungry game impl
        elif gamemode == "wtf":
            print("WTF mode")
            return WTFGame(motor_controller, rgb, laser, buzzer)
        else:
            print("Default mode")
            return DriveGame(motor_controller, rgb, laser, buzzer)
```

This function is a simple `if`/`else` block that instantiates the correct game class to return based on the `gamemode` parameter.  This is where you would instantiate your custom game mode.

If this `setGameMode()` returns your custom game class instance, then it will have its `setup()` function called almost immediately, and its `onHit()` function will be called whenever it gets hit and `onFire()` will be called when the fire button is pressed.

### What you have to change

So, to implement your own game mode, you need to:
1) Create your own class that extends the `BaseGame` class
2) Update the `setGameMode()` to instantiate your class and return it.

For instantiating your game mode, you will most likely have to replace an existing game mode in the `setGameMode()` function.  Or make it the new default and return it in the final `else` block.

### Enhancements

To make things more interesting you may want to implement new methods on the `MotorController` class in [motor_class.py](/code/motor_class.py) or Buzzer class that you can call in your `onHit()` function.

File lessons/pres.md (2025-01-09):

presentation fly-over:

- intro slides - hi, we're the mad scientists

- high level blink test

- explanation of parts/shark overview?

- work through instructions at your own pace if interested to learn how components work and such, otherwise dig into building

- we will start a mad scientist mars laser party at 1 hour before finish.

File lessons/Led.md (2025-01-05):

# LED

An LED is a Light Emitting Diode.  A diode only allows electricity to flow in one direction.  So, there is a positive and negative side to the LED.  Typically the longer leg of the LED is the positive side.

So, for this lab, we will simply hook our LED to the Pico to see it light up. 

## What to do

For this lab, we are going to start by just using the Pico as a power source to light up our LED.  

## Orientation

It will be easiest if you orient your Pico as seen below in the [wiring diagram](#wiring-diagram).   
The USB connection should be at the top, but touching the table and the pins should be sticking straight up.

## Wiring Diagram

Plug a red wire from the longer leg on the LED to the 3.3V pin on the Pico. And a black wire from the other leg to a GND (ground) pin on the Pico.  

NOTE: Technically the color of the wires you use doesn't matter (internally they are the same), but the color does make it easier to know their purpose.  Usually, red wires indicate positive(+) and black or white wires indicate ground/negative(-). 

See Diagram:

LED Wiring Diagram

When you plug the wires into the LED you should see it light up.  If you accidentally plug the wires in backwards (long leg to ground), then that shouldn't hurt anything, but the LED won't light up because a diode only allows electricity to flow in one direction.

## Voltage Considerations

LED Specification

LEDs (like most electronics) have voltage ranges in which they are designed to run. As mentioned above, we are currently running off 3.3V (volts), but if we look at the specifications for the LEDs, we will see we are actually running a little over the specified voltage range of 3.0 to 3.2V for our blue LED. This is why it's so bright. It's running slightly above max power! 

Notice that the white, blue, and green LEDs support up to 3.2V. The other LEDs (red and yellow) only support up to 2.2V.  So, if we tried to use a red or yellow LED with our current circuit we could burn them out.

Since we are barely over spec with our blue LED we most likely won't have an issue, but it would be safer for the lifespan of the LED to run at a lower voltage. 

## Resistors

 One simple way to lower the voltage in a circuit is to use a resistor.  A resistor simply resists (or restricts) the flow of electricity. You could use a resistor to lower the voltage to safer levels, but we are going to be lazy and try a different approach when we use the 2 volt LEDs.

Resistor

For now we will continue using the blue LED which can handle the 3 volts from the Pico and NOT use a resistor.

# Controlling LED with PICO

Now we will look at how to use code on the Pico to control an LED.

Grab your blue LED or any LED rated for 3 volts.  Take a red wire and connect the long leg of the LED into the GP16 pin on the Pico.  "GP " stands for General Purpose Input Output.  Connect the short leg of the LED to a GND pin on the Pico.

Blink Diagram

With the LED in place and connected to the Pico and to ground, we just need to write the code. 

``` Python
from machine import Pin
import utime

led = Pin(16, Pin.OUT)

while True:
    led.toggle()
    utime.sleep_ms(1000)
```

Enter the code above into the editor and then click the Play button.
If everything works, you should see the LED flash about once a second.

If it works, blink twice!

## Other Pin functions

Another way to turn the LED off and on is to use the [value() function](https://docs.micropython.org/en/latest/library/machine.Pin.html#machine.Pin.value).

Here is that code:

``` Python
from machine import Pin
import utime

led = Pin(16, Pin.OUT)

while True:
    led.value(1)
    utime.sleep_ms(1000)
    led.value(0)
    utime.sleep_ms(1000)
```

Try this out.  If you want it to blink faster change the time it sleeps.

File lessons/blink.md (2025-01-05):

# First Time With the Pico!

## Overview

We will write our first bit of code in Python to run on the Pico and flash its onboard LED!  This is the obligatory blink demo for nearly all microcontroller projects... this is the equivalent of the "Hello world!" program.

## Raspberry Pi Pico WH

We are using the Raspberry Pi Pico WH which is part of the Raspberry Pi Foundation's new microcontroller family of boards... You can read more about them here.

[Official Pico Page](https://www.raspberrypi.com/products/raspberry-pi-pico/)

## Python

If this is your first time playing with Python you may find this cheatsheet helpful:

[Python Cheatsheet](https://www.pythoncheatsheet.org/)

 ## What to do

Connect your Raspberry Pi Pico to your computer via  USB cable and open Thonny.  If you don't have Thonny installed or haven't flashed the Pico to use Python follow this guide: [Thonny Setup](https://github.com/javaplus/MadScientist/blob/main/lessons/firmware.md)

In Thonny, go to the bottom right hand corner and choose the interpreter for Thonny to use.  If your computer recognized the Pico, you can choose the item that says "**MicroPython(Raspberry Pi Pico)** in the list. (see image below)

Thonny Select Pico

Note: if this is your first time launching Thonny you may have to click past the Welcome/language selection splash page.

If it's able to connect, you should see the Shell print a message like the one shown in the picture above that tells you the version of MicroPython running on the Pico.
The Shell is a [REPL](https://pythonprogramminglanguage.com/repl/) where you can type Python statements and have them be executed immediately.  We are not going to use the Shell.  Instead, we will type our code into the text editor area above the Shell.

Here is the obligatory blink demo for the Pico W (note that it's different for the standard Pico):

``` Python
from machine import Pin
import utime

led = Pin("LED", Pin.OUT)

while True:
    led.toggle()
    utime.sleep_ms(1000)
```
A note about the code above:

You'll notice that there is a `while True` statement at the end.

`while True` means loop forever. The `while` statement takes an expression and executes the loop body while the expression evaluates to boolean "true". `True` always evaluates to boolean "true" and thus executes the loop body indefinitely.

This is the section of the code that our Pico will run forever and ever, over and over again.  
(Unless we define a way for it to break out)

Enter the code above into the Thonny editor and then click the Play button.
If everything works, you should see the onboard LED flash green about once a second.

**NOTE**: You can save this code to your Pico, by clicking the blue Save button in Thonny and then choosing to save it on the Pico.  Give it a file name and a ".py" extension.  If Thonny complains about the Pico or device being busy OR you think it's stuck processing somewhere, click the red STOP button to exit running the current program and then click Save. The STOP button resets the connection with the Pico. Once you have saved a file in Thonny, usually clicking the "Play" button will automatically save the latest version again as well as run it.  This may change with different releases of Thonny. So, if you need to save your code, click the Save button before closing Thonny to ensure a proper save.

Thonny Save and STOP Buttons

If it works, eat a snack or better yet, give your instructor one!

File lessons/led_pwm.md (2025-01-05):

# PWM (Pulse Width Modulation)

## Overview

Now we will look at how to use PWM (Pulse Width Modulation) with the Raspberry Pi Pico.  If you aren't familiar with PWM just think of it as a way to send a pulse of power at regular intervals.  PWM is a more efficient way of powering electronics like motors or even LEDs.  Instead of providing constant power to a device you can send pulses of electricity to keep a motor running or light up an LED. That is, you can specify a frequency at which to send pulses of electricity and then fluctuate the amount of time that signal or power is on during each pulse.  The amount of time the power is on during each signal/pulse is called the **duty cycle**.  The image below from [circuitdigest.com](https://circuitdigest.com/tutorial/what-is-pwm-pulse-width-modulation) illustrates PWM signals using various duty cycles. **NOTE**: The frequency rate isn't shown below, but it doesn't matter. The duty cycle is independent of the frequency.

PWM

If powering a motor with PWM, the higher the duty cycle the faster the motor will spin.  
If powering an LED with PWM, the higher the duty cycle the brighter the LED will be.
This is caused by an increase in the average output voltage. (You will see this happen during this lab!)

 ## What to do

In this lab, we will use PWM via the code on the Pico to dim and brighten an LED. Compared to the earlier lab when we lit an LED, we will be making several changes.
The first change we will make is to slightly alter the way we are interacting with the GPIO pin connecting to our LED. In the previous lab, the GPIO pin was configured as a simple output pin, in which we would set the value to 1 (or high) to turn the light on, or set the value to 0 (or low) to turn the LED off.  So, in our previous implementation it was strictly a binary operation.

With PWM, we will be able to change the frequency and the duty cycle.  That is, how many pulses per second (frequency) we send and how long the power will be high during each pulse (duty cycle).  Initially, we will just make a few tiny changes to keep the functionality of LED toggling off and on, but we will use PWM to light up the LED.

The wiring diagram is the same as the previous LED lab:
Wiring Diagram

## The Code

So, to start we need to import [PWM](https://docs.micropython.org/en/latest/library/machine.PWM.html?highlight=pwm) from the machine library.  So, alter the first import by adding "PWM" alongside the existing "Pin".  The altered import line should look like this:

```Python
from machine import Pin, PWM
```
Next we will alter the initiation of the "led" variable to use PWM.  To do this, we simply create a Pin with our pin number and wrap that with "PWM()".  
Alter the "led" initialization line like this:
```Python
led = PWM(Pin(16))
led.freq(1000)
```

Here we define Pin #16 as our pin to use for PWM signals.  We also set the frequency to 1000Hz. That's 1000 pulses per second.  

Since our `led` variable is now a PWM object, the `value()` function is invalid.  So, we need to update each place we were calling the `value()` function, to use the [duty_u16()](https://docs.micropython.org/en/latest/library/machine.PWM.html?highlight=pwm#machine.PWM.duty_u16) function.

This function allows us to set the duty cycle.

The lowest possible value is **0**... but we can also use 0%.

The highest possible value is **65535**... but we can also use 100%. 

Therefore, if we want our LED to be at the brightest level, replace `led.value(1)` with `led.duty_u16(65535)`.
To turn the LED completely off, replace `led.value(0)` with `led.duty_u16(0)`.

Here's the full code:

```Python
from machine import Pin, PWM
import utime

led = PWM(Pin(16))
led.freq(1000)

led.duty_u16(0) # init LED to off

while True:
    # turn LED on full
    led.duty_u16(65535) 
    utime.sleep_ms(500)
    
    # turn LED off
    led.duty_u16(0)
    utime.sleep_ms(500)

```

After updating the code, click the STOP button to reset and then click the Play button to run the new code.

If everything is working, then you should see the LED flash on and off, but it is now using PWM.

Not super exciting yet, but wait - there's more!

## See the Power of PWM!

To see some differences between PWM and pure binary on/off, try playing with the value passed to the `led.duty_16(65535)` method.  Replace **65535** with a lower value so that when the LED comes on, it's not as bright.  Something like this:

```Python
    led.duty_u16(5000) # 65535 is max
```

Retest with different values to see how they affect the brightness of the LED.

After you are bored with that, let's make some cool affects with PWM.

What we'll do now is make pressing the button slowly increase the brightness of the LED to max, and then pressing it again slowly dim the LED till it's off.

To do this, we will simply add a `for` loop in the block of code that turns the LED on/off to slowly adjust the duty cycle up or down.  Here's an example `for` loop to slowly increase the brightness:

```Python
       for duty in range(0,65535,1):
            led.duty_u16(duty) # 65535 is max
```
**NOTE**: The 3rd parameter of the for loop is the step.  That is how much to count by.  If you want to count by 5's, then change the 1 to 5.

Here's an example for loop to slowly decrease the brightness:

```Python
       for duty in range(65535,0,-1):
            led.duty_u16(duty) # 65535 is max
```

You can swap out the code that turns the LED on and off with these loops to see the LED more slowly light up and dim down.  These `for` loops may still cause it to light up and dim quickly.  Can you think of how you could slow the lighting up or dimming down?

Here's the full code:

```Python
from machine import Pin, PWM

led = PWM(Pin(16))
led.freq(1000)

led.duty_u16(0) # init LED to off

while True:
    # slowly brighten
    for duty in range(0,65535,1):
        led.duty_u16(duty) # 65535 is max

    # slowly dim
    for duty in range(65535,0,-1):
        led.duty_u16(duty) # 65535 is max

```

If you got this to work, eat some gummies!

## Stretch Goal

Play with the for loops and optionally some sleeping in your for loop to get the LEDs to light up or dim slowly.

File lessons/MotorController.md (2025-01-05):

# Motor Controller (mini L298N)

L298N Motor Controller

The mini L298N is a small DC motor controller that allows you to use a microcontroller to control the speed and direction of up to 2 attached motors.

It does this by having paired inputs (labeled `IN1`, `IN2`, `IN3`, and `IN4`).  `IN1` and `IN2` are used to control `MOTOR-A`.  And `IN3` and `IN4` are used to control `MOTOR-B`.
Adding power to one of the pins in a pair (e.g. `IN1`) would cause the motor connected to `MOTOR-A` to move in a direction.  Cutting power to `IN1` and adding power to `IN2` would cause the motor connected to `MOTOR-A` to move in the opposite direction.
The same applies to the second pair `IN3` & `IN4`, just that it controls the motor on `MOTOR-B`.  If you want a pin to move the motor in a different direction, either switch the connections on the motor or the `IN*` pins.

You should only put a signal/power to one of the paired pins at a time.  Meaning you'd never want to put power to both `IN1` and `IN2` as that would not make sense.  You'd want power to go to one or the other in order to control the direction.
You can put power to one of the first pairs and one of the second pairs at the same time.  Just not power to both pins in a pair.

# Wire it up!

Wire the Pico to the motor controller and wire one motor to the `MOTOR-A` connector.  How you connect the motor wires to the `MOTOR-A` pins doesn't matter.  That is, there isn't a right or wrong way to connect the motor wires.  If you reverse the wires it will just cause the motor to spin in the opposite direction.

Note that the Pico is upside down, with the pins sticking straight up.  The diagram has the Pico in this orientation as well.  That is, the Pico in the diagram is showing you the correct pins if it is upside down with the pins up and the USB connection at the top. Also note that the two wires connecting the motor to the motor controller need to be connected from the **bottom** of the controller, instead of from the top (the diagramming program we use does not allow us to show this).

L298N Motor Controller

# Code

Here is the code that simply sends full power to `IN1` or `IN2` at a time.  It loops continuously and turns the motor forward, then stops, and then backward.  "Forward" and "backward" are really relative at this point and don't really matter.  The motor should turn in different directions when `forwardFull()` is called versus when `backwardFull()` is called.

```Python
from machine import Pin, PWM
import utime

print("Running Simple Motor Test")

in1 = Pin(16, Pin.OUT)
in2 = Pin(17, Pin.OUT)

def forwardFull():
    print("in forward full")
    in1.low()
    in2.high()
    
def backwardFull():
    print("in backward full")
    in2.low()
    in1.high()

def stop():
    print("in stop")
    in1.low()
    in2.low()

while True:
    forwardFull()
    utime.sleep_ms(3000)
    stop()
    utime.sleep_ms(3000)
    backwardFull();
    utime.sleep_ms(3000)
    stop()
    utime.sleep_ms(3000)
```

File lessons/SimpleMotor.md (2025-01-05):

# Electric Motor

DC (direct current) electric motors are great for adding movement to your projects.  Simple electric motors like the ones we will be using have only two connections.  Connect these wires to a power source and the motor will start moving.  Be careful though to use a power source that is appropriate for your motor. You don't want to burn out the motor with too much voltage. 

## N20 Electric Motor

N20 Electric Motor

We are using the GA12-N20 Motor.  They are metal geared high torque motors and can typically support from 3V up to 12V of power.  There are many versions of the N20 motors.  The ones we are using can turn about 100 RPM (revolutions per minute) at 3 volts.  The motors in your kit should not be used with more than 5 volts.  The Raspberry Pi Pico GPIO pins output 3.3 volts and can be controlled programmatically, but the VBUS pin outputs a steady 5 volts. However, the pins on the Pico are designed for very low power devices like LEDs or sensors and are not recommended to run electric motors.  So, caution needs to be taken when using electric motors with the Pico to not draw too much power (amps) through the board.  A small motor with little load (no resistance) should be fine for our quick test, but we will show you the correct way to power a motor using the Pico later.  For now, let's focus on understanding how simple electric motors work and just be sure there's nothing restricting your motor's movement during this lab; otherwise, you may release the [magic smoke](https://en.wikipedia.org/wiki/Magic_smoke) from the Pico.

## Try it out
To test our electric motor, we will simply plug our Pico in via USB which will immediately provide a steady 5 volts of power on the VBUS pin. We can use this to temporarily test our motor.

At this point, we are just using the Pico as simple battery source.  So, connect one wire from the motor to the VBUS pin and the other to a ground pin.  It doesn't matter which wire you connect from the motor to the VBUS versus to ground. You are just providing a flow of electricity through the motor.  It can spin in either direction depending on the way the power flows.

Wiring Diagram for Motor

As soon as you connect the wires of the motor to the Pico, you should see the motor spinning.  If you reverse the wires, you should see them spin in the opposite direction.  

## Resources

[Data sheet for N20 motor](https://abra-electronics.com/electromechanical/motors/gear-motors/mini-metal-gearmotors/ga12-n20-3v100.html)

[Another Data sheet for N20 motor](https://temperosystems.com.au/wp-content/uploads/2021/03/N20-Micro-Speed-Gear-Motor.pdf)

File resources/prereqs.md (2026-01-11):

# Prerequisites For Mad Scientist Shark Rover Lab

## Overview
For this lab, you will be assembling and coding a Raspberry Pi Pico powered Shark Rover.  The hardware and parts will all be provided.  You will need to have a laptop that can access the internet to get the directions and the code.  The code is in micro Python.  For these labs, you do NOT have to be a Python expert. You can actually get by fine without having ever done Python programming before. We will provide all the code required to get your Rover working.  You do have the option to extend or add to the code to create your own game modes.  So, if you want to get a little familar with Python before coming you can check out this free tutorial get comfortable with Python. [Python Tutorial](https://www.learnpython.org/)

## What you need

### Thonny
You just need the simple Python editor [Thonny](https://thonny.org/) which allows you write code on your laptop and execute it on the Pico via a USB cable. USB cables will be provided just make sure you have a laptop with Thonny installed and an available USB A jack on your laptop. We will have a few USB C to USB A adapters for those with only tiny ports. If you require a special dongle to connect a USB A cable into your laptop, be sure to bring it.

Please download and install the latest version(4.x or higher) of Thonny.
[Download Thonny](https://thonny.org/)

### Mobile app

To control your completed shark rover, you most likely want to use our mobile app.  The directions to install it can be found here: [Mad Scientist Controls](https://github.com/javaplus/mad_scientist_app)

## But I want to use VS Code (Alternative to Thonny)

Thonny is very basic and is not a robust IDE. If you'd prefer to use VS Code, you can, but you will need to add an extension to allow VS Code to deploy the code on the Raspberry Pi Pico.
If you decide to try to do this lab in VS Code, I'd recommend still having Thonny installed as a back up incase the VS Code extension cannot properly connect to the Pico.

Here is the VS Code extension: [MicroPico VS Code Extension](https://github.com/paulober/MicroPico?tab=readme-ov-file)

Link to VS Code: [VS Code Download](https://code.visualstudio.com/download)

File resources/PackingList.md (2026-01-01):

# Packing list:

## Main Electronics 

### Chassis:  
- [ ] 1 Pico
- [ ] 2 Motors
- [ ] 1 Motor Controller
- [ ] 1 USB Cable
- [ ] 1 9Volt Battery

### Lighting:
- [ ] 1 laser
- [ ] 1 Photo Res with 10Kohm resistor

## Wires(All Female to Female):

- [ ] 3 x Red 10cm
- [ ] 3 x Black or White 10cm
- [ ] 3 x Blue 10cm
- [ ] 2 x Green 10cm
- [ ] 1 x Yellow 10cm
- [ ] 1 Red y female to female (from voltage reg to pico and motor controller)
- [ ] 1 Battery connector with y connector on ground  

## Main 3D Printed Parts    
- [ ] 1 Chassis
- [ ] 1 Pico Plate
- [ ] 4 x wheels
- [ ] 2 tranny inserts
- [ ] Chin/Front Connector
- [ ] Teeth Gums
- [ ] Shark Head with Eyes
- [ ] Shark Body
- [ ] Shark Tail
- [ ] Tail tip
- [ ] RGB holder
- [ ] Front Connector
- [ ] Rear Connector
- [ ] Battery door
- [ ] Battery door key
- [ ] Switch holder

#### Treads  
- [ ] 2 treads

## Small Parts Cup
- [ ] 2 RGB LEDs 
- [ ] 4 Plate plugs 3D printed parts
- [ ] 1 Power switch
- [ ] 1 Printed Power Switch Extender
- [ ] 1 Voltage regulator
- [ ] 1 Buzzer(optional)
- [ ] 2 Blue LEDS(optional)
- [ ] 2 LEDs other color(optional)
- [ ] 2 Hex Plugs

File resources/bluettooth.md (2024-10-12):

Bluetooth Pico W guide that's complicated: https://www.raspberrypi.com/news/getting-to-grips-with-bluetooth-on-pico-w/

Bluetooth Example two way communication: https://www.kevsrobots.com/blog/two-way-bluetooth.html
Github repo for two way bluetooth: https://github.com/kevinmcaleer/pico_two_way_bluetooth/blob/main/pico_a.py
Video for Bluetooth two way communicatioon with two picos: https://www.youtube.com/watch?v=l-K_0N1m5kQ

aioable docs(bluetooth wrapper library in python): https://github.com/micropython/micropython-lib/blob/master/micropython/bluetooth/aioble/README.md

BlueTooth Spec docs:  https://www.bluetooth.com/wp-content/uploads/Files/Specification/HTML/Assigned_Numbers/out/en/Assigned_Numbers.pdf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

MicroPython Bluetooth docs: https://docs.micropython.org/en/latest/library/bluetooth.html#bluetooth.BLE.gatts_register_services

### Testing Bluetooth 

Web Bluetooth samples: https://googlechrome.github.io/samples/web-bluetooth/

Web Bluetooth tutorial
https://novelbits.io/web-bluetooth-getting-started-guide/

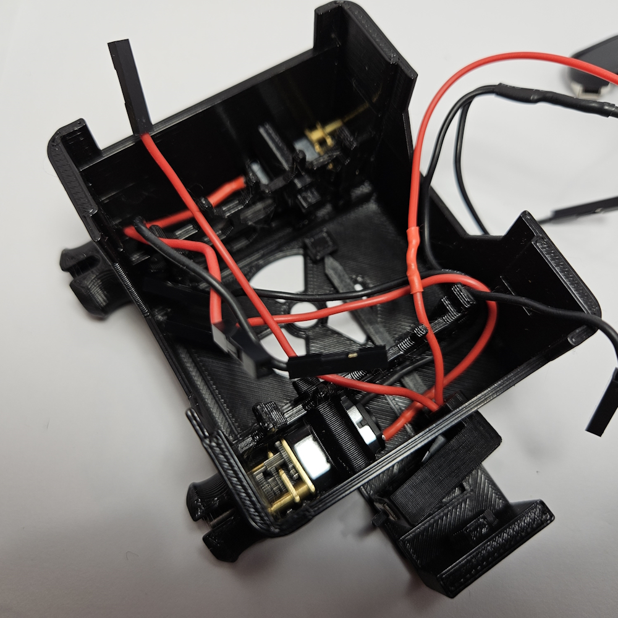
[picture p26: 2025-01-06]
lessons/images/assembly/chassis_power_switch_topdown.jpg

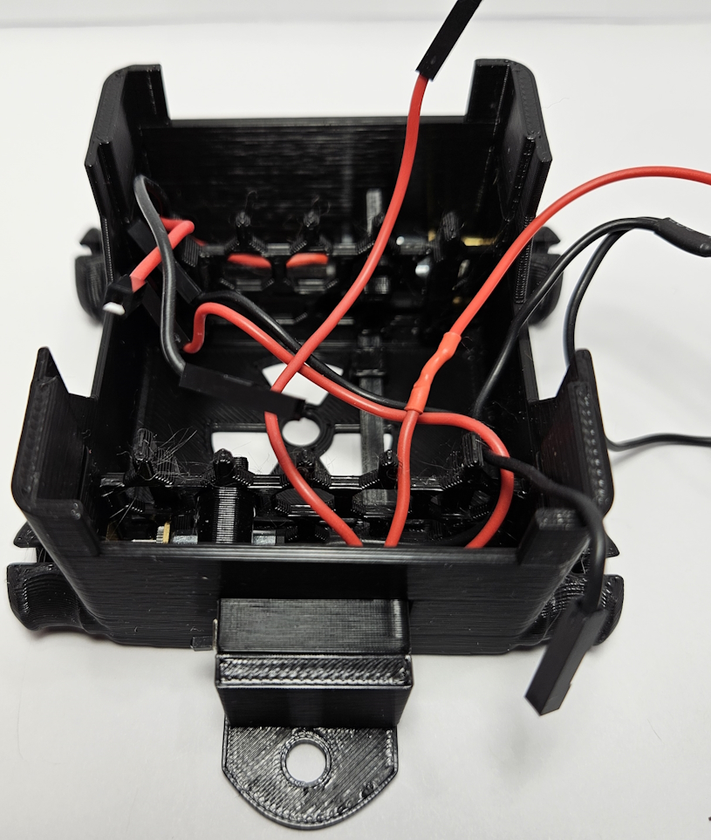
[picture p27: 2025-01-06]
lessons/images/assembly/chassis_power_switch_battery_door.jpg

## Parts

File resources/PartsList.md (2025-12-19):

# Parts List for JAWS Rover

## Electronics
- 1 x Pico W(with headers) - INFO | [ORDER](https://www.pishop.us/product/raspberry-pi-pico-wh-pre-soldered-headers/)
- 2 x N20 Mini Micro Metal Gear DC Motor (3V, 100RPM) - [ORDER](https://www.aliexpress.us/item/2251832836005412.html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)
- 1 x H Bridge Motor Driver Board L298N mini - [ORDER](https://www.aliexpress.us/item/3256806563796055.html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)
- 1 x 9V Battery Snap Connector clip - [ORDER](https://www.aliexpress.us/item/2251832639224754.html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)
- 1 x L7805CV Voltage Regulator 1.5A 5V - [INFO](https://www.quarktwin.com/blogs/integrated%20circuit/l7805cv-pinout-a-comprehensive-guide-to-understanding-and-using-l7805cv-voltage-regulator/245) | [Order](https://www.aliexpress.us/item/3256806581142509.html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)
- 1 x 9 Volt Battery
- 1 x Photoresistor 5528 - [ORDER](https://www.aliexpress.us/item/3256805782399608.html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)
- 1 x Mini Laser Pointer 3V - [ORDER](https://www.aliexpress.us/item/2251800404204813.html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)
- 2 x 5mm full-color LED RGB (Transparents Cathode) - [ORDER](https://www.aliexpress.us/item/3256805804520441.html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)
- 10K Ohm Resistors
- Many - 10cm super flexible wires [ORDER](https://www.aliexpress.us/item/3256806939512527.html)
- 1 x Box : [ORDER](https://www.amazon.com/gp/product/B0C1MW7RXZ/ref=ppx_yo_dt_b_search_asin_title?ie=UTF8&th=1)

## 3D Printed Parts
- 1 x Chassis
- 1 x Pico Plate
- 2 x tracks 
- 4 x wheels
- 2 x tranny inserts
- 1 x head/eyes
- 1 x gum teeth
- 1 x chin front connector
- 1 x RBG holder
- 1 x shark body(Cap)
- 1 x shark tail
- 1 x tail tip
- 1 x Rear Connector
- 1 x Battery Door
- 1 x Battery Door Key
- 1 x Switch Holder
- 1 x Switch Extender
- 2 x Hex Plugs(hold motors)
- 4 x pico pins
  
## Parts per kit:

#### Chassis:
- 1 Pico
- 2 Motors
- 1 Motor Controller
- 5 10cm Wires(fom Pico to Motor controller)
- 1 10cm Red from switch to voltage regulator
- 1 Battery connector with y connector on ground
- 1 switch
- 1 Voltage regulator
- 1 Red y female to female (from voltage reg to pico and motor controller)

#### Small Parts

- 2 RGB LEDs 
- 4 Plate plugs 3D printed parts
- 1 Power switch
- 1 Voltage regulator

#### Lighting:
- 2 RGB LEDs
- 4 20cm or 10cm female to female
- 1 Photo Res with 10Kohm resistor
- 1 laser

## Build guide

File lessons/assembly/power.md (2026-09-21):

# Power 

### Power Switch

### Parts
- 9 volt battery connector
- Power switch
- Power switch holder
- 10cm red female to female wire

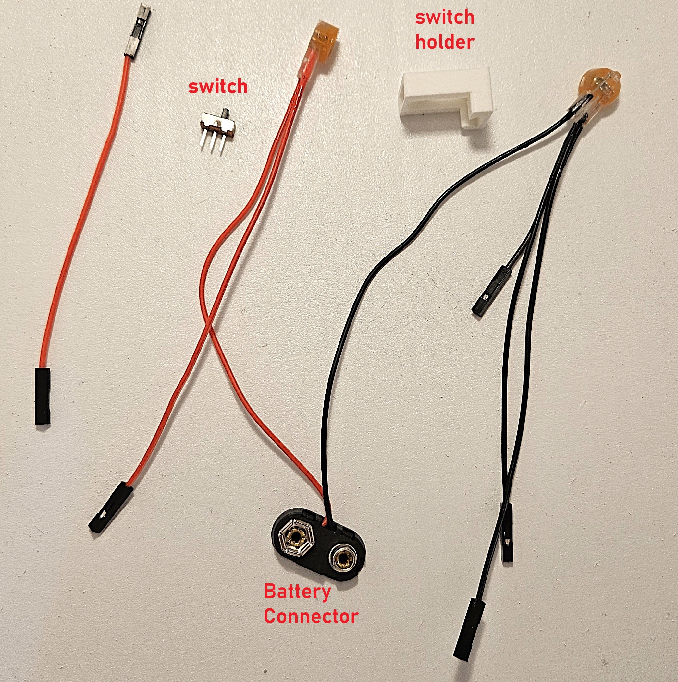
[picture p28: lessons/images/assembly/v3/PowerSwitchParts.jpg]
Power components


Feed the red wire from the battery connector and one end from the 10cm red wire through the slot in the front of the chassis:

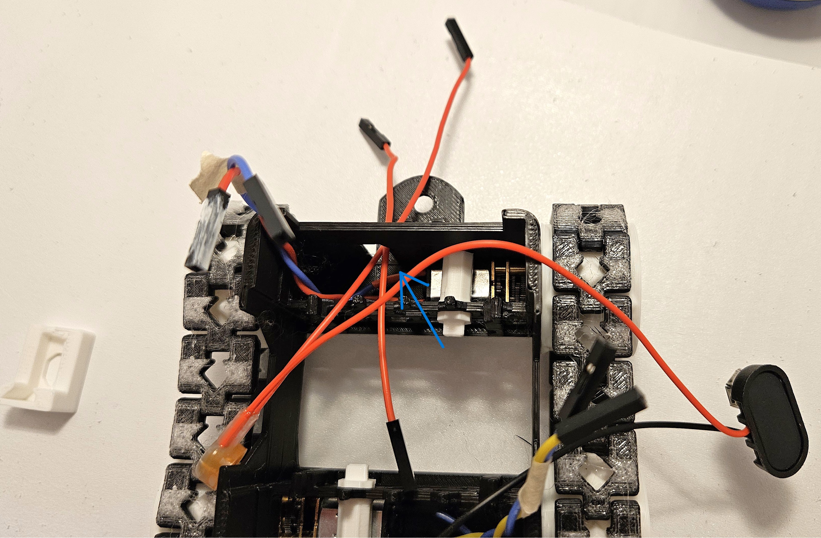
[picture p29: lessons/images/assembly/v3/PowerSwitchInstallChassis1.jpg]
Front Chassis Power Wire


Make sure the wire from the battery connector comes out from the inside of the chassis. The battery connector itself should be inside the chassis.

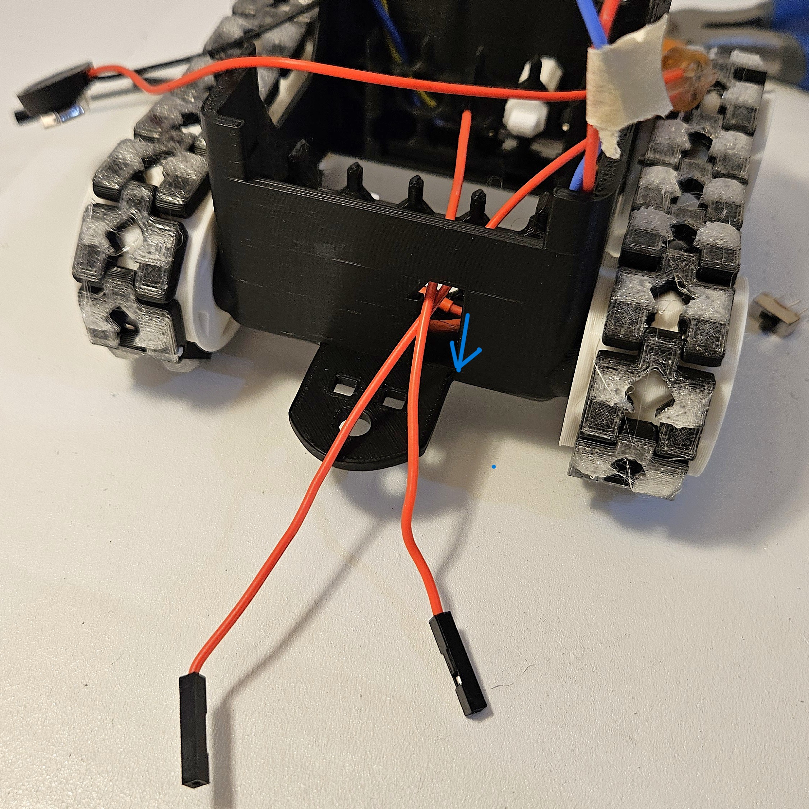
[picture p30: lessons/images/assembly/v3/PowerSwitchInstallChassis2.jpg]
Front Chassis Power Wire2


Get the power switch holder and feed the two red wires through the rectangular hole at the edge of the power switch.  

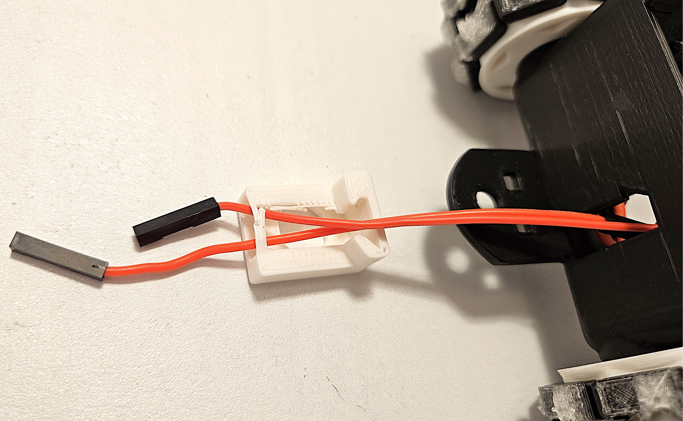
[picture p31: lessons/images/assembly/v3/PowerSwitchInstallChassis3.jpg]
Switch wires through switch holder


Connect one wire to the middle pin, and the other to either side.  The side that you connect the second or outer wire to will determine where the switch needs to be in order to be "on".

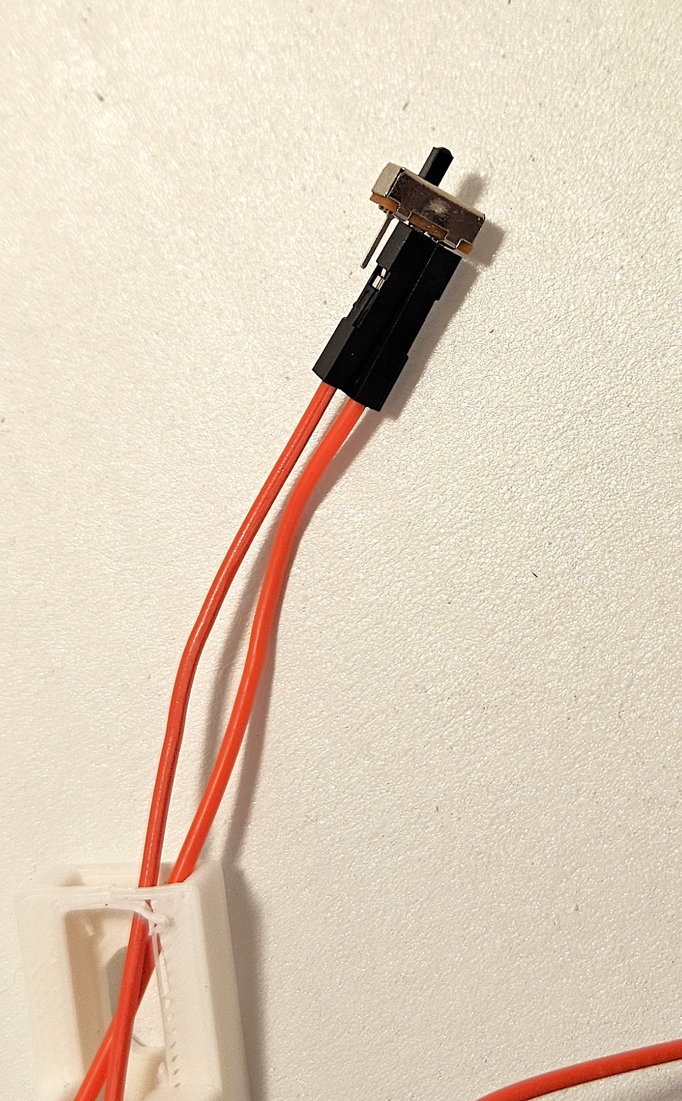
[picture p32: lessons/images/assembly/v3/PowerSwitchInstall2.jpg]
Switch wires Installed


The switch simply connects the two pins closest to it. For example, in the picture above, since the edge pin to the right is connected to the red wire, and the switch is pushed to the left, that means the switch is off.
Make a note of which direction is off and on.  Off will be when the switch is in the direction of the empty pin not connected to a wire. Put the switch in the OFF position now and try to leave it OFF until much later in the build when you are told to turn it ON.  
  
Now push the power switch and wires into the rectangular slot, pushing the red wires against the angled piece.  The red wires should make a sharp right angle inside the switch holder.  This helps hold the wires in place.  This can be a tight fit. See more instructions after picture if struggling.

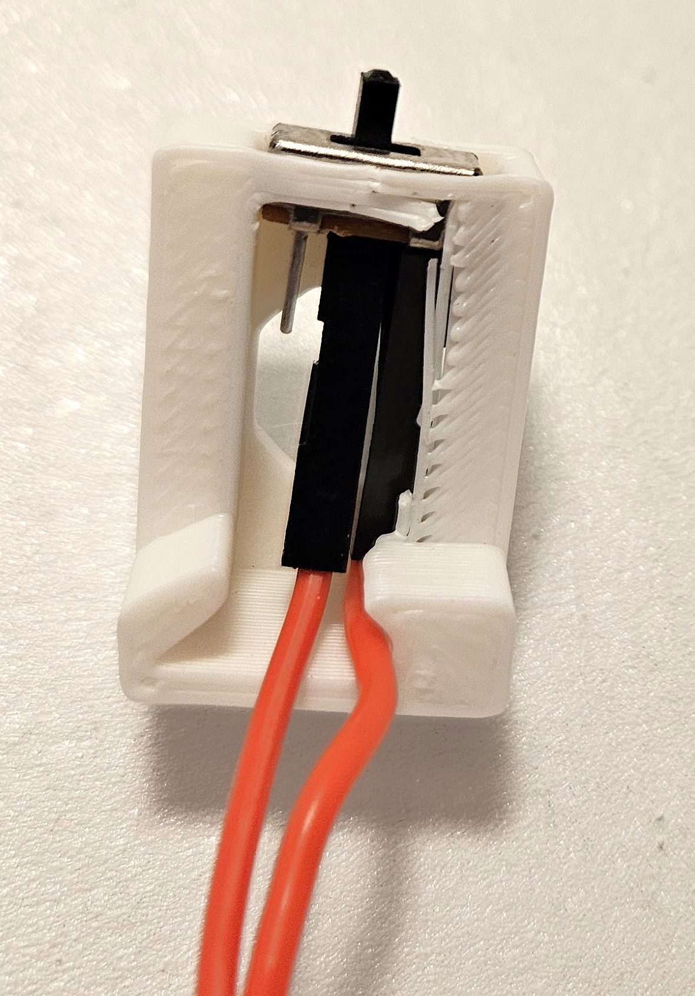
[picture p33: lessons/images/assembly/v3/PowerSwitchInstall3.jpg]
Switch in switch holder


Fitting the power switch in the switch holder can be a very tight fit.  Borrow a pair of pliers or use two strong thumbs on each side of the black switch to push it into place.

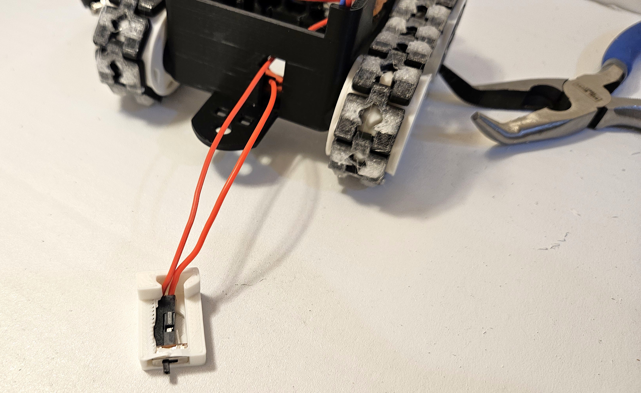
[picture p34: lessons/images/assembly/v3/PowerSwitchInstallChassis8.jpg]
Switch in switch holder second view


<details >
<summary>Good Unit Test Opportunity</summary>
    After the power switch is securely in the power switch holder and connected to the 10cm red wire and the battery connector, this is a good time to test that your switch is working and making a continuous connection when on. Grab a lab instructor if available to help here. To do this, take a voltmeter or something similar to test continuity (Diode mode will work too).   The idea is to turn the switch to the on position and put the voltmeter leads on the positive battery connector and then the other end on the loose end of the 10cm wire to ensure that electricity can flow through the switch from the battery and out through the 10cm wire. 
</details>  

Now gently pull the red wires from inside the chassis to pull the switch holder assembly up against the outside of the chassis. The protruding side of the switch holder(where the wires are coming out) should fit into the slot on the chassis.

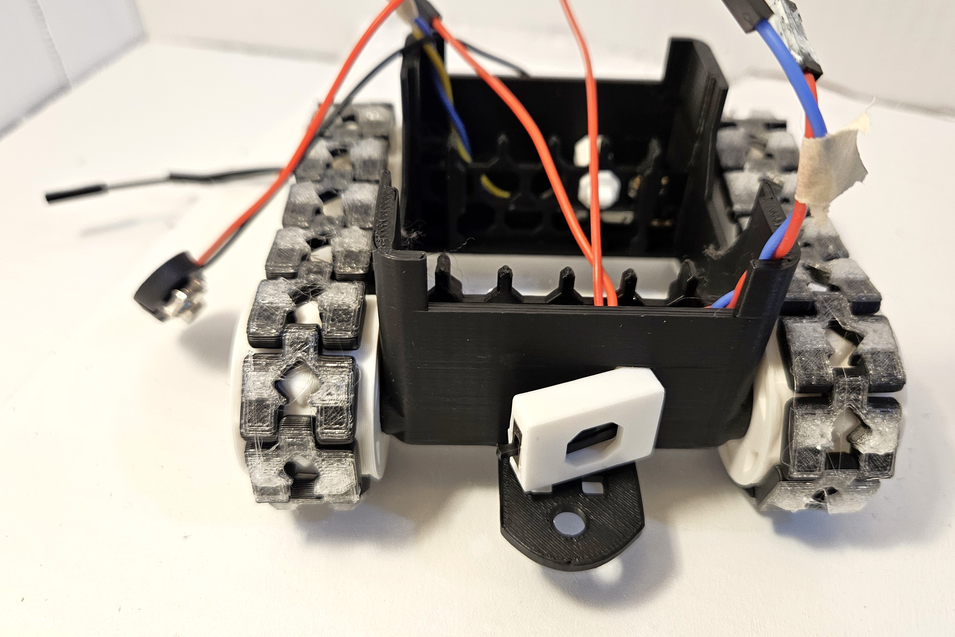
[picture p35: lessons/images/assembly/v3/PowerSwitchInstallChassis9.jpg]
Switch in chassis


### Battery Door Install  
### Parts
- Battery door
- Switch Key

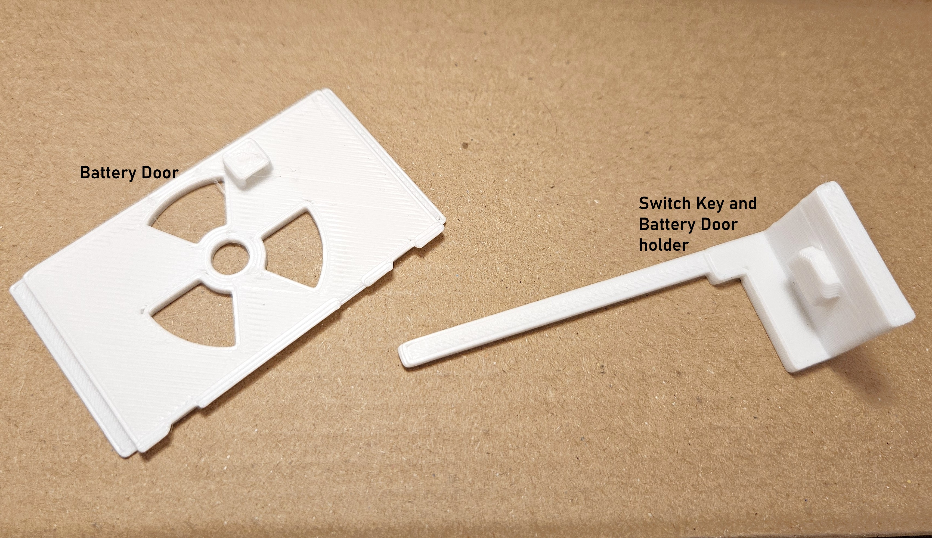
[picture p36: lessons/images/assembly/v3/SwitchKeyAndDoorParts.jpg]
Battery Door


Put the battery door under the bottom center of the chassis with the raised square section up and towards the front (away from the hitch). 
The tabs on the battery door opposite the raised square go into the chassis first and act as a hinge point.  In the picture above, the tabs are on the right side.
Put the tabs up into the chassis and then pivot the raised square side up to be flush with the chassis.
While holding it there, take the switch key and guide the long "sword" like end under the switch holder already on the chassis.
The long narrow "sword" part should slide just under power switch holder through the same slot in the chassis that power switch holder is in.  This will lock it in place.

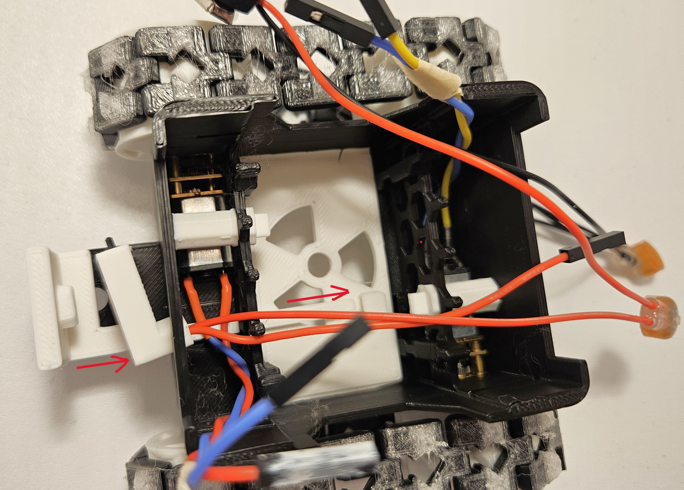
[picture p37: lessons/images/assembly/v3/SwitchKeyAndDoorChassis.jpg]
Switch in chassis


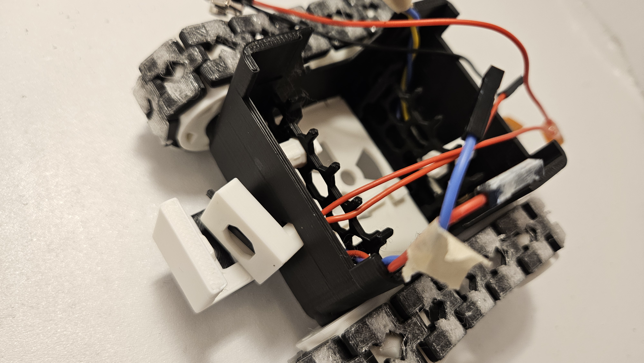
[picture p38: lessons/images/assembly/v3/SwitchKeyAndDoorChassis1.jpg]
Switch in chassis view 2
  
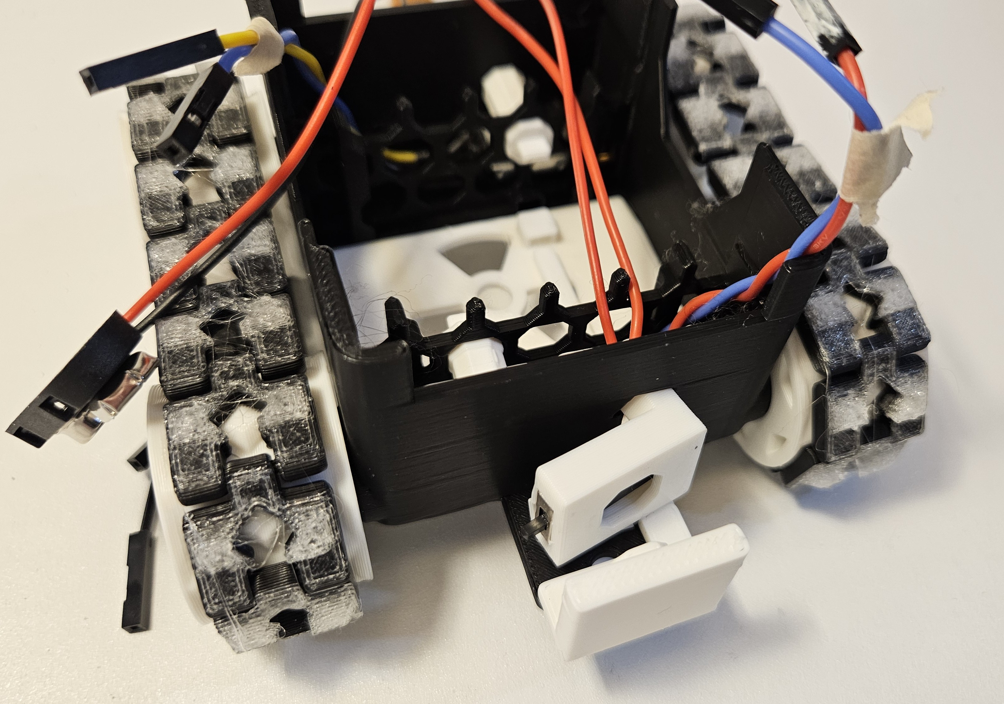
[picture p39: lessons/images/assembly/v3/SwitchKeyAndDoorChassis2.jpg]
Switch in chassis view 3
  

Continue to slide the battery key through until it holds the switch holder in place and the hex shape on the key fits into the similarly shaped hole on the switch holder.  

Battery door and key fully installed:  

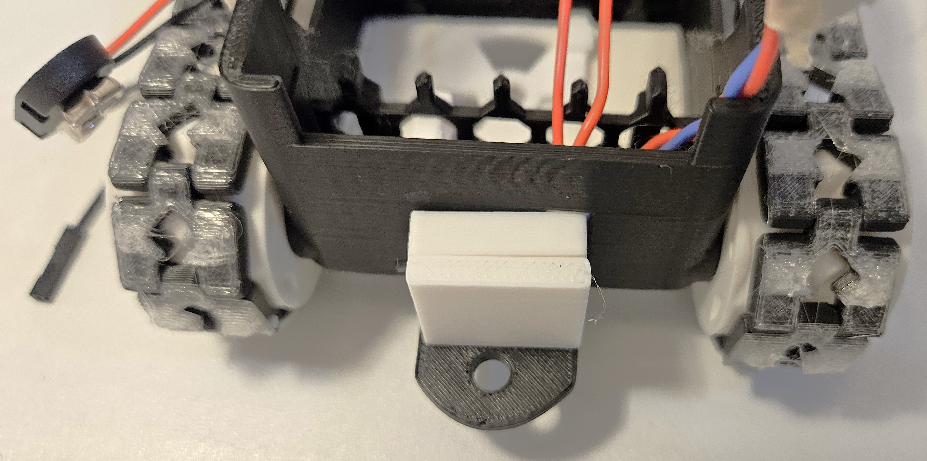
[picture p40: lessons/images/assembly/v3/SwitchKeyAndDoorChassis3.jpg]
Switch fully installed


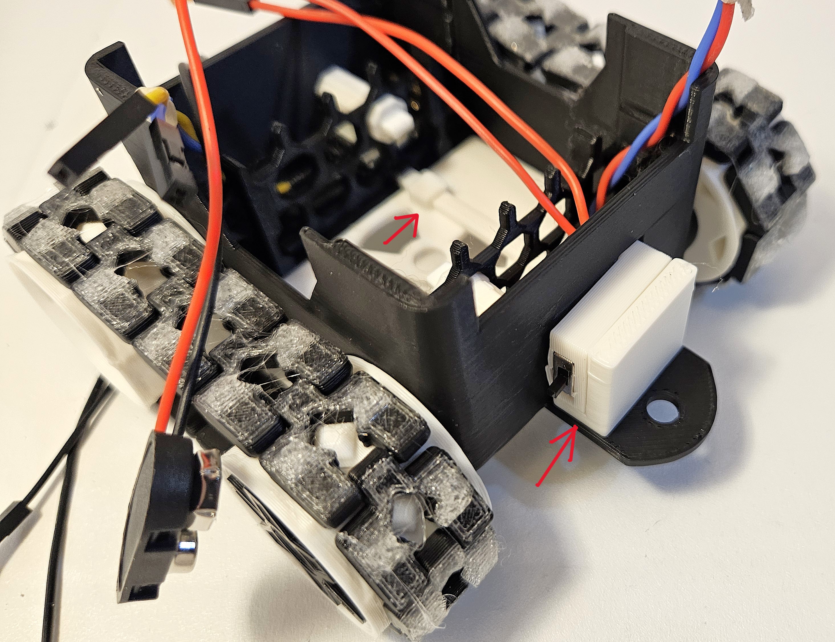
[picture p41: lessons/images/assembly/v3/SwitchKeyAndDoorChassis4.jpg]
Switch fully installed second view


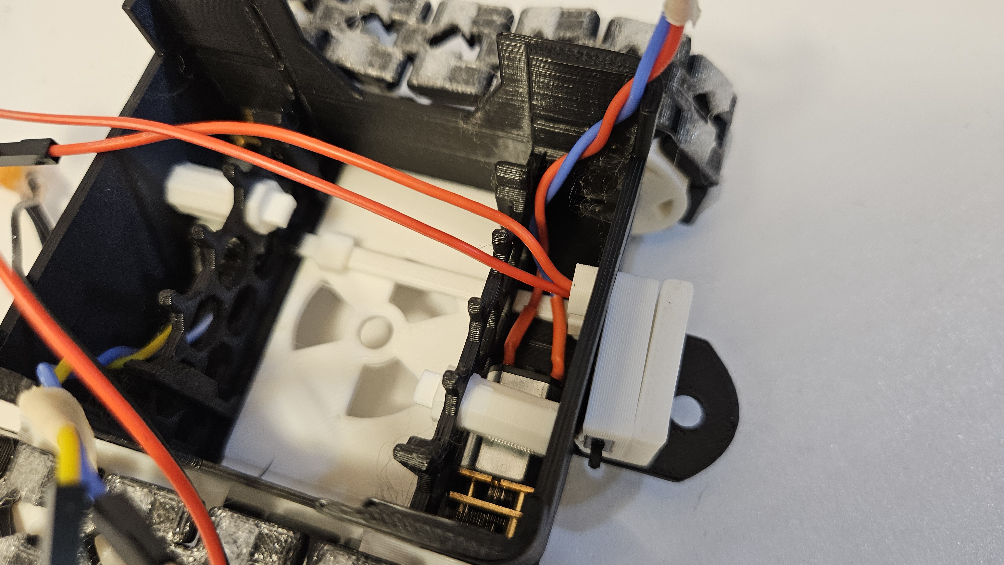
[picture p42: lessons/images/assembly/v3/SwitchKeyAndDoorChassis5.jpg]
Switch fully installed third view


At this time, make sure the switch is turned off.  To turn off the power switch, push it in the direction of the single free pin not connected.

### Positive Power Connections
### Parts:
- 10cm Red Female to Female wire
- 10cm White Female to Female wire
- 10cm 3 way connector

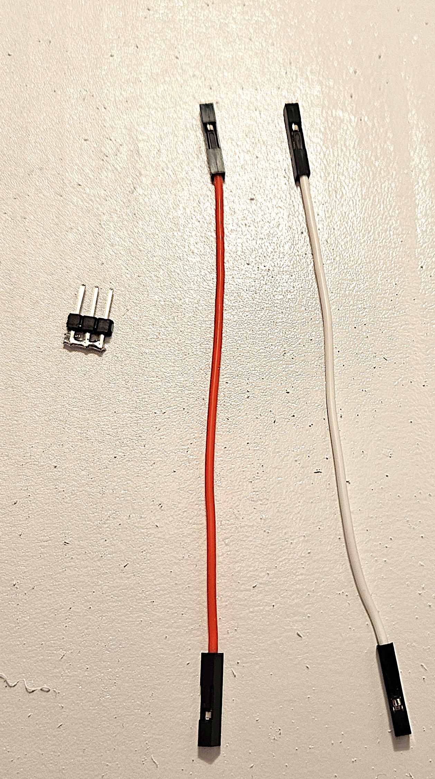
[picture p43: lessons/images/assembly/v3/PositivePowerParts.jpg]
Positive Power Parts


Take the two 10cm female to female wires and connect them to the 3 way connector.     

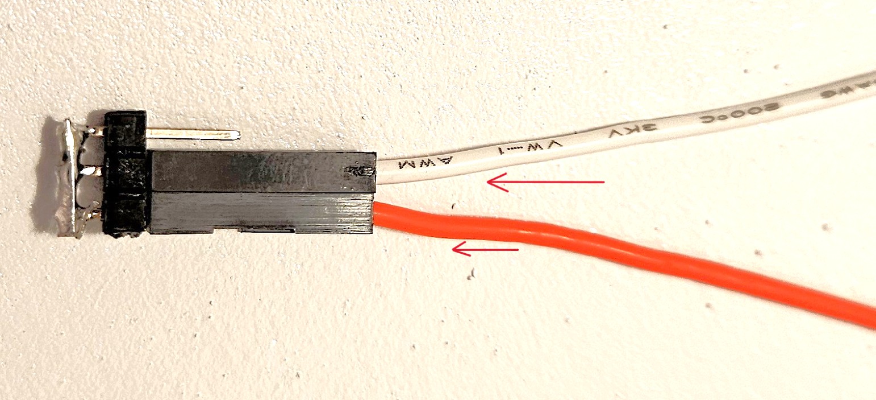
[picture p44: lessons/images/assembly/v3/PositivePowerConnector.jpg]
Two wires on connector


Now plug unconnected end coming from the switch into the 3 way connector.  This should be the 10cm red wire that is connected the switch.  Plug it's free end that is inside the chassis into the 3 way connector.  

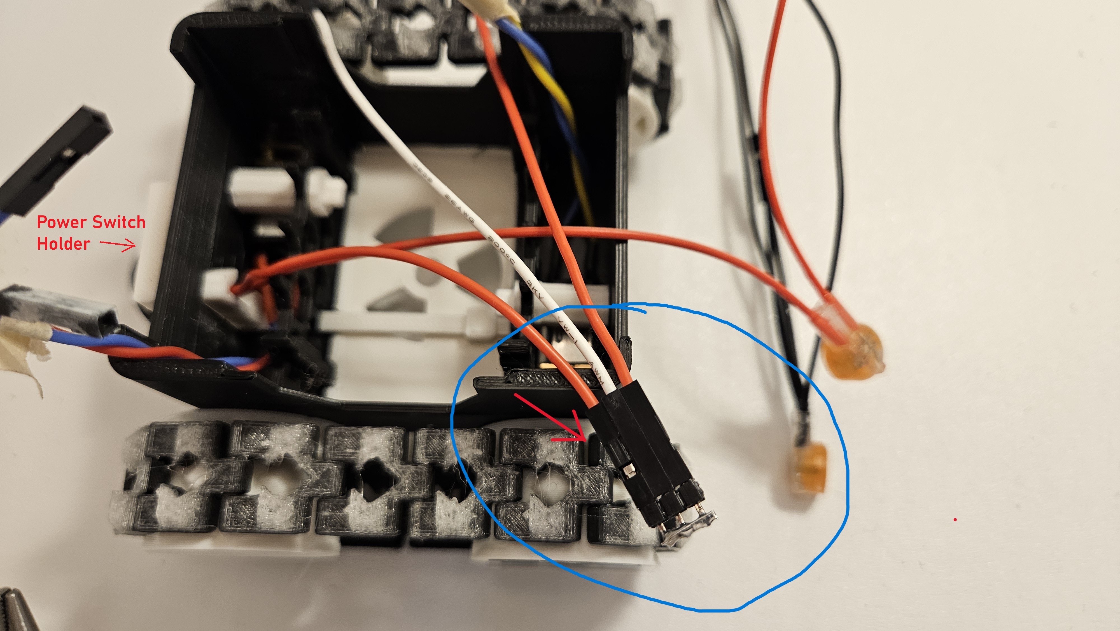
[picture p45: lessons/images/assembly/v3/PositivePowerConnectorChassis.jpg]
Switch wire on connector
  

Now we will use a small piece of tape to hold the 3 wires on the 3 way connector and cover any bare metal on the connector. So, take a small piece of tape and place it on the 3 ends of the wires and make sure it goes past the end of the connector.  

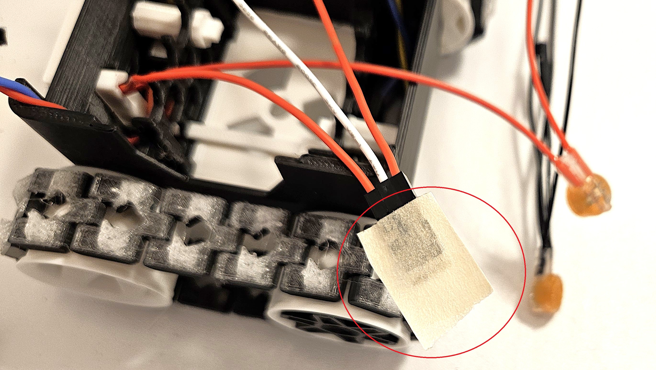
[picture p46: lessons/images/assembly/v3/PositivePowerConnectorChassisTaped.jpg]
Tape connector 1
  

Now wrap the tape around the connector and over onto the other side of the wire ends.  Again ensure that all bare metal is covered otherwise you could cause a short and damage electronics.

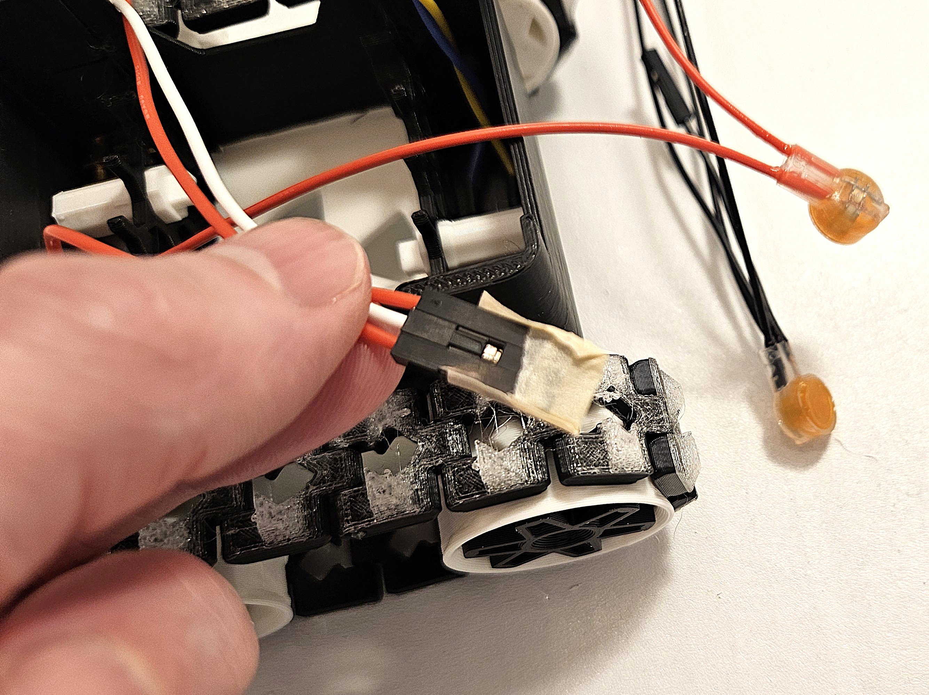
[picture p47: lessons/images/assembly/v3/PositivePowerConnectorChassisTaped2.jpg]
Tape connector wrapped
  

### Voltage Regulator Install

The voltage regulator converts our 9 volt power source down to a steady 5 volts, which is what is required to operate the Pico.

Grab the voltage regulator and 10cm red female to female wire.  
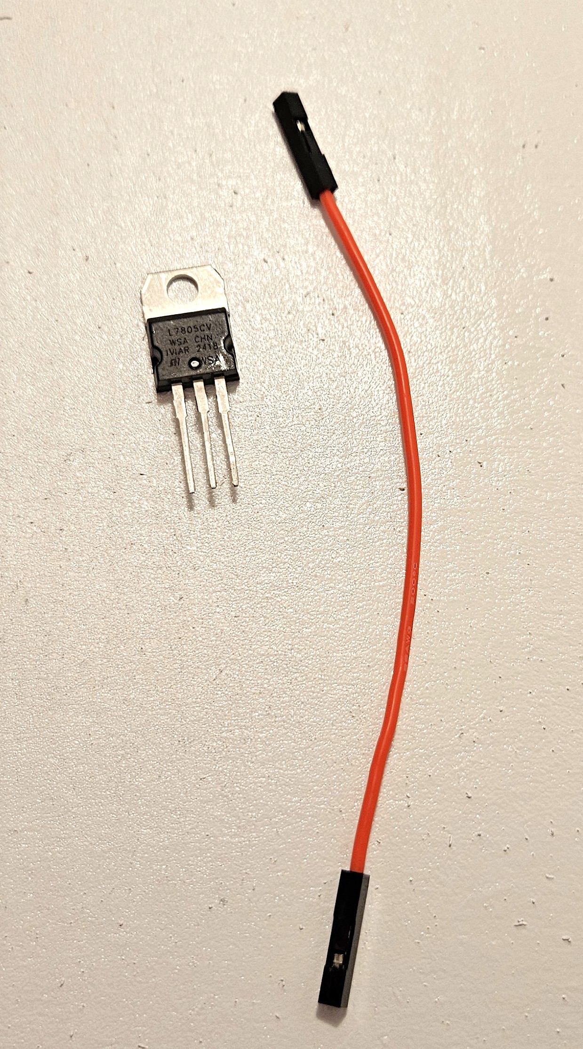
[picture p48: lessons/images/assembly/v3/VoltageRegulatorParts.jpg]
Voltage Regulator parts


The 3 pins from left to right are our input, ground, and output as seen in the picture above.

Connect your red female to female wire to the right most pin.  If the wire is too tight to fit on or too lose try rotating the wire connector 90 degrees and re-insert the wire onto the voltage regulator pin.  Try to push the wire up onto the pin as much as you can but be careful not to bend the pins on the voltage regulator or poke yourself. If you do slightly bend the pins, it's not a big deal, just gently bend them back flat.  Constantly bending the pins can weaken them.

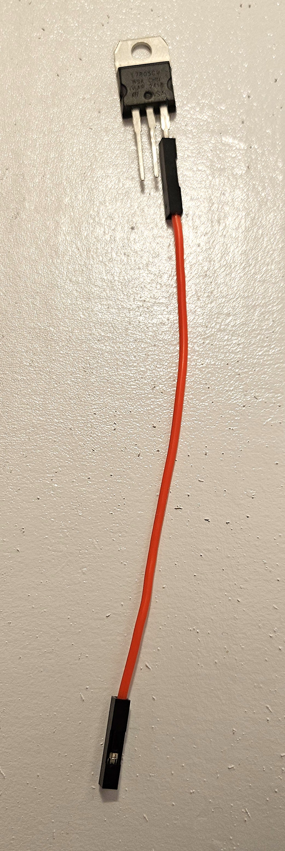
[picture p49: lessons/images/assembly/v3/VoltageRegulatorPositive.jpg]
Voltage Regulator Right wire connected


Now take the one of the black wires from the battery connector and connect it to the middle pin on the voltage regulator.  Use the shortest of the black wires.  Again, remember to rotate the wire connector 90 degrees if you struggle to get a good fit.

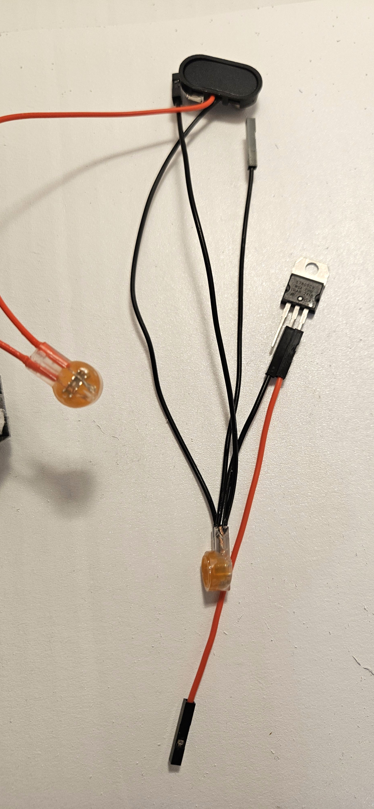
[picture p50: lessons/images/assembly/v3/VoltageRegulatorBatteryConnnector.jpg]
Voltage Regulator ground wire connected


Now take the red wire from the 3 way connector and connect it to the left most pin (the only free pin) of the voltage regulator.

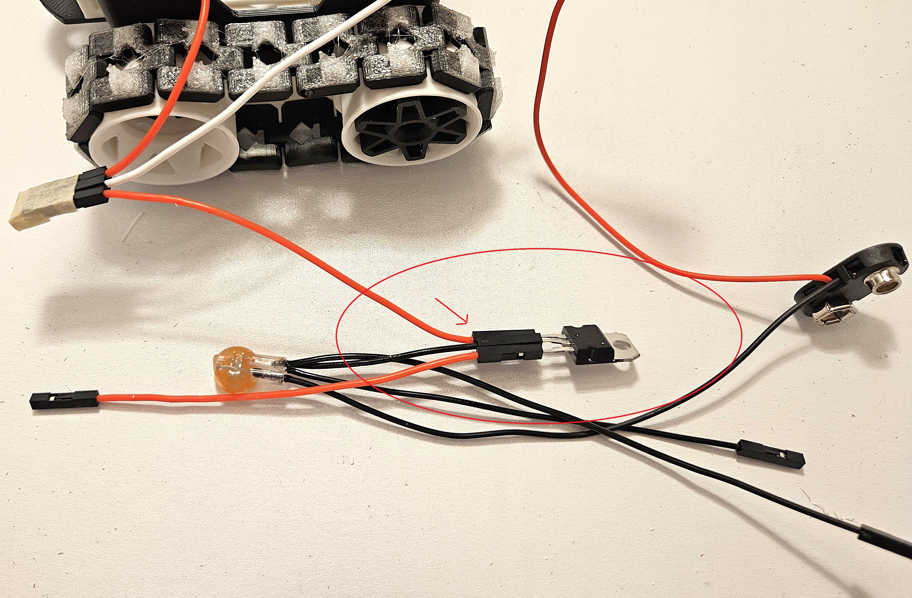
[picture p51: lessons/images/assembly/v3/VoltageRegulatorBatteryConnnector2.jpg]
Voltage Regulator input wire connected


Now we need to tape the voltage regulator wires.  Take a small piece of tape and put it over the wire ends and the bare pins from the voltage regulator as seen in the picture below.

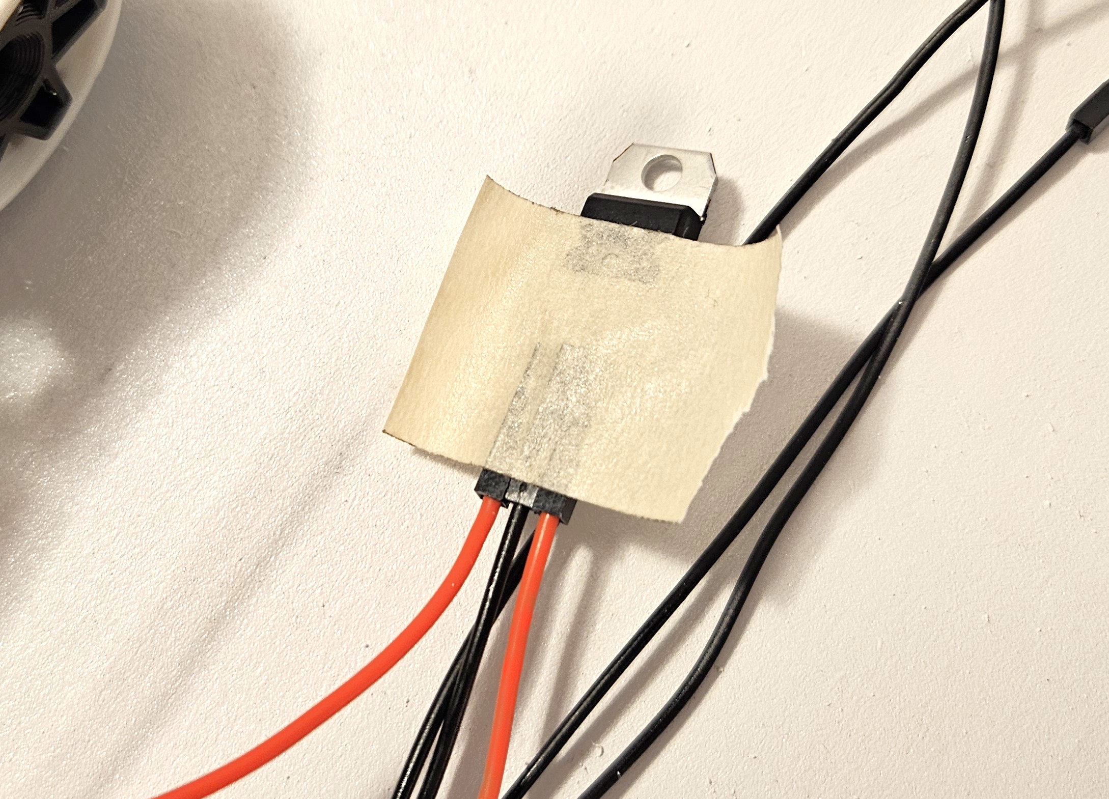
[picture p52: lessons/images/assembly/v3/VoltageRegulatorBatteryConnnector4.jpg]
Voltage Regulator input wire connected


Now wrap the tape around to cover the back as well as seen in the image below.  This is to keep the wires on the voltage regulator as well as keeping anything from touching the bare pins and causing a short.

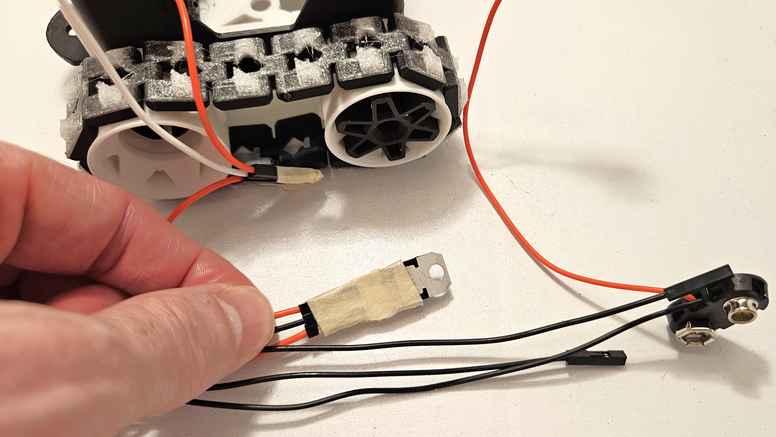
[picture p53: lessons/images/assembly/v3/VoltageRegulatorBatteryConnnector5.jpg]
Voltage Regulator input wire connected


### Battery Install

Make sure your power switch is still in the off position. Grab your battery and connect it to the battery connector:

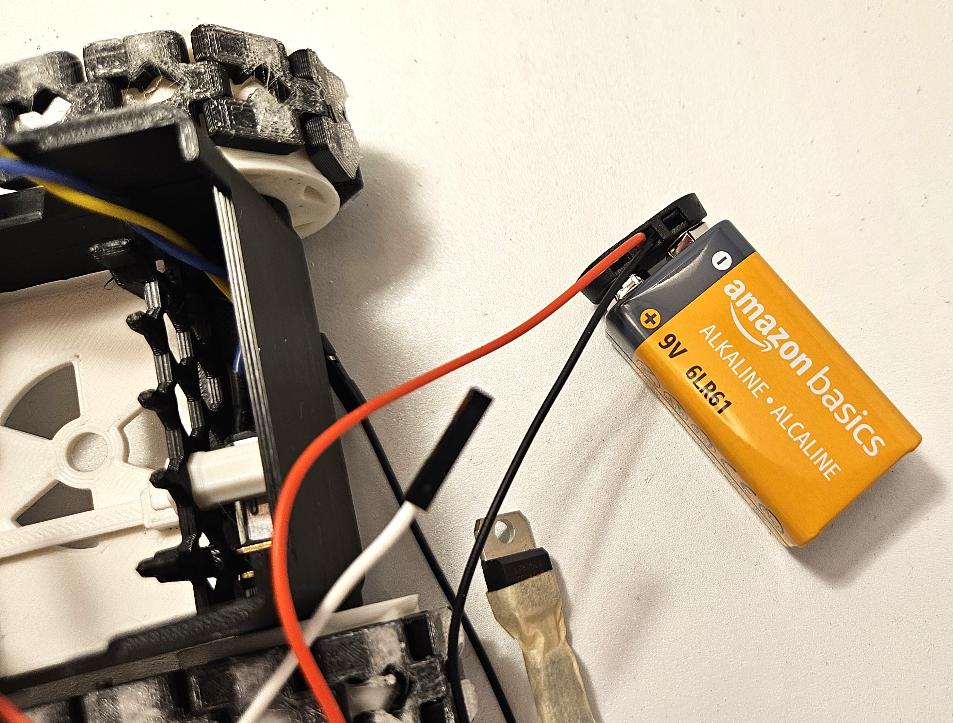
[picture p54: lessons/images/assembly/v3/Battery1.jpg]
Battery Connected


Now let's go ahead and install the battery.  While the top pico plate is off, it's easiest to install the battery through the top.    
<details>
<summary>Removing the Battery</summary>
After your Rover is built, you will be accessing the battery through the bottom by removing switch key. To allow the battery door to come off.  
</details>  

Put the battery flat on top of the battery door as you see in the picture below.  Make sure no wires are under the battery.

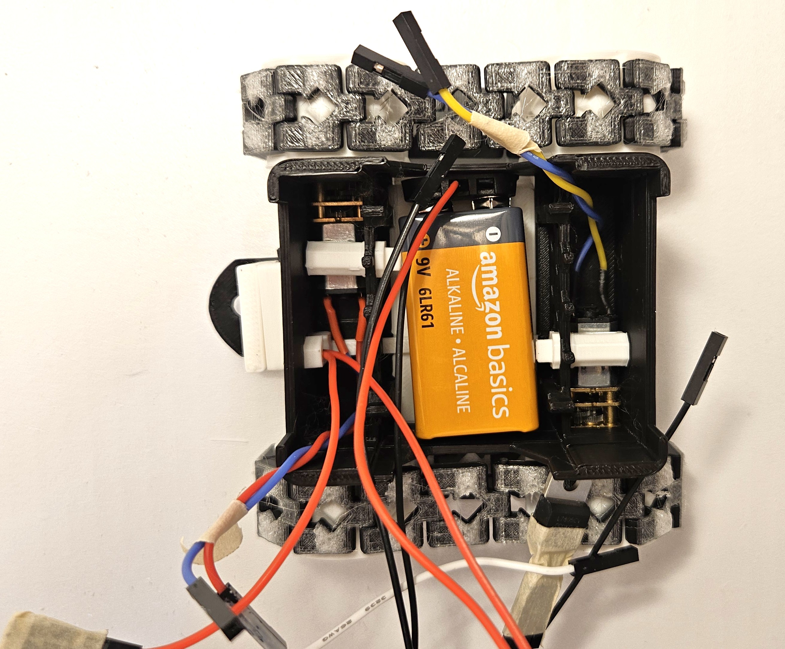
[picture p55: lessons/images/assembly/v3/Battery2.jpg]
Battery In Chassis


Now move the voltage regulator on top of the battery.  Use one of the pegs on the chassis to set the voltage regulator on. Allow the peg from the chassis to go through the hole in the top of the voltage regulator as seen below. Make sure the voltage regulator is flat with it's taped pins over the battery.  

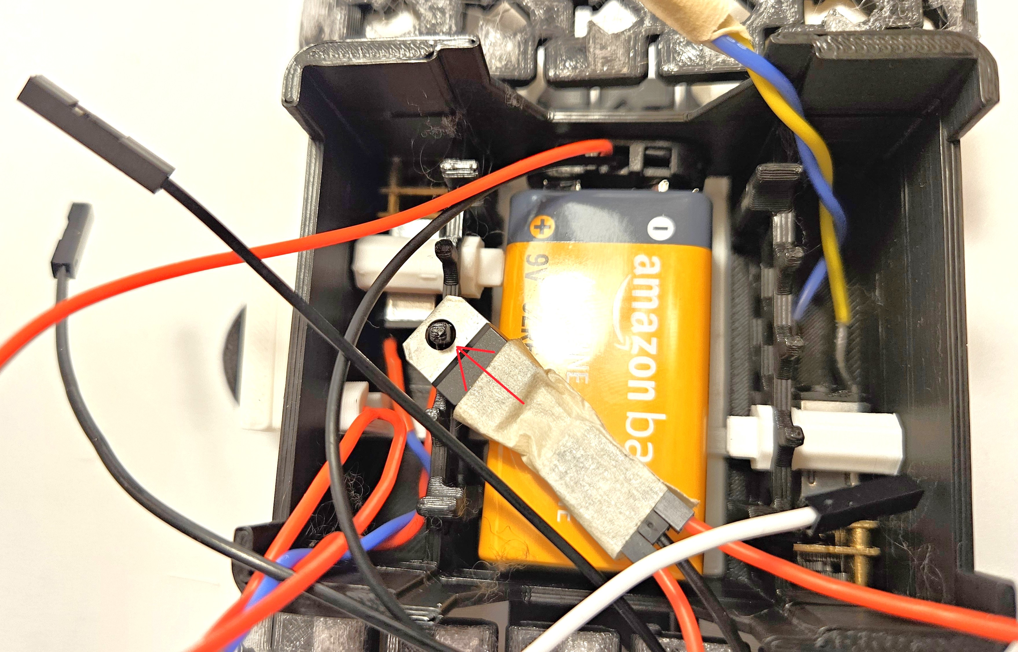
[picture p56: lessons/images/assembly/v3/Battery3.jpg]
Voltage Regulator On Battery


This completes this part of the installation.  If possible use a voltmeter to test

[back](https://github.com/javaplus/MadScientist/blob/main/lessons/assembly/wheels.md)

[next](https://github.com/javaplus/MadScientist/blob/main/lessons/assembly/plate_chassis.md)

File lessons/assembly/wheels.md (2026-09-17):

# Wheels and Tracks

### Wheels and Transmission

### Parts

- 4 wheels
- 2 transmission pieces

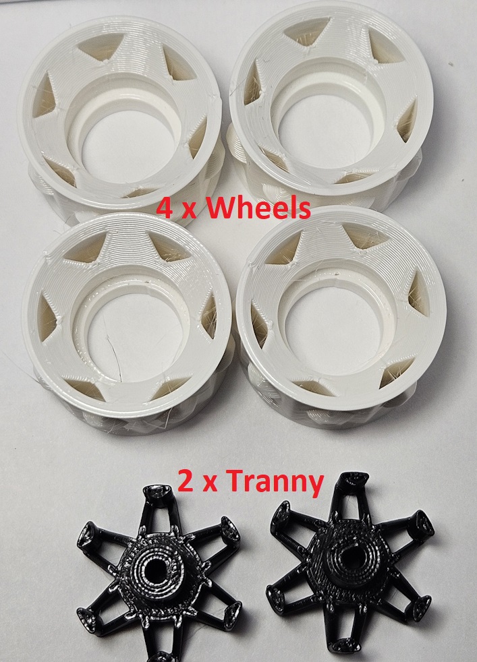
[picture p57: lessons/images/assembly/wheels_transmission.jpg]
Wheels and Transmission


Now let's install the wheels.  

Take your 4 wheels and snap them on the chassis.  Make sure the flat side is against the chassis.  Once they snap on, give them a spin with your hand to make sure they can spin freely without much resistance. 

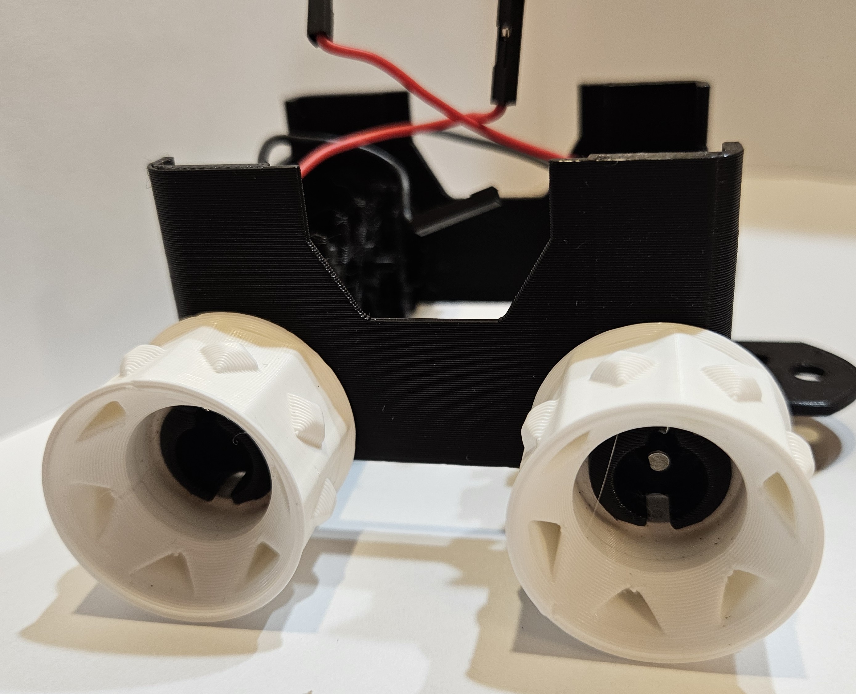
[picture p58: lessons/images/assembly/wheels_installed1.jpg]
Wheels installed 2


Now install the 2 transmission pieces.  The axles have a D shape.  The transmission parts have a D shaped slot in the center.  Match the holes to put the transmission onto the axle.  
The easiest way to do this is to start inserting the transmission piece into the wheel until it hits the axle while holding the motor from sliding back.  Then rotate the wheel and the transmission till the D shaped hole and the axle line up and you can push the transmission in flush with the outside of the wheel.

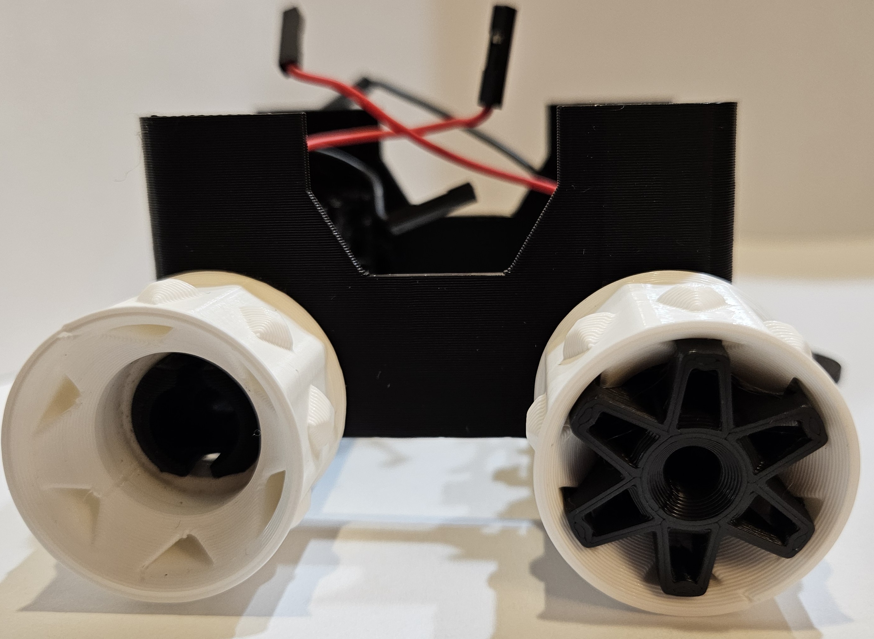
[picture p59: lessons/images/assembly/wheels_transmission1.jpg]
Transmission installed


### Tracks

### Parts
- Track pieces (2 tracks)
- 2 small pieces of 3D printer filament

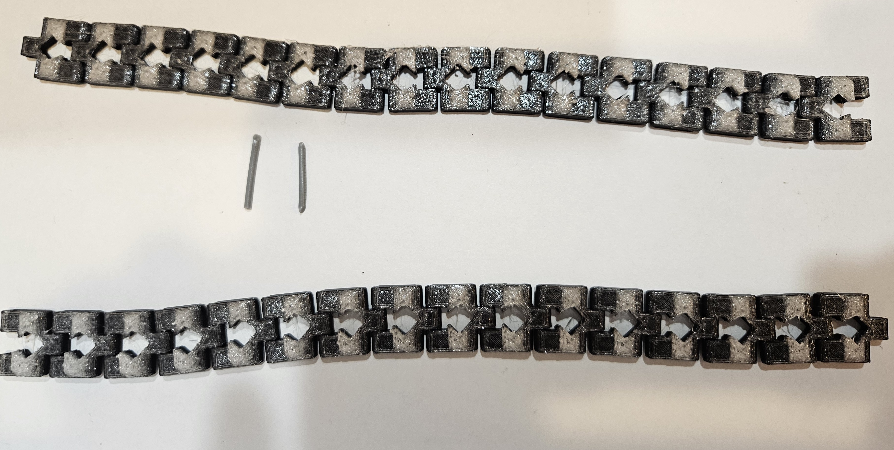
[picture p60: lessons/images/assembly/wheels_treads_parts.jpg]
Track Pieces


Before putting the tracks on the wheels, test putting your small piece of filament through the holes on each end of the tracks.  Due to 3D printing variables, there can be some material left in the holes that need cleaned out. So, shove your filament through the holes, to ensure a clean hole and the ability to get the filament through.

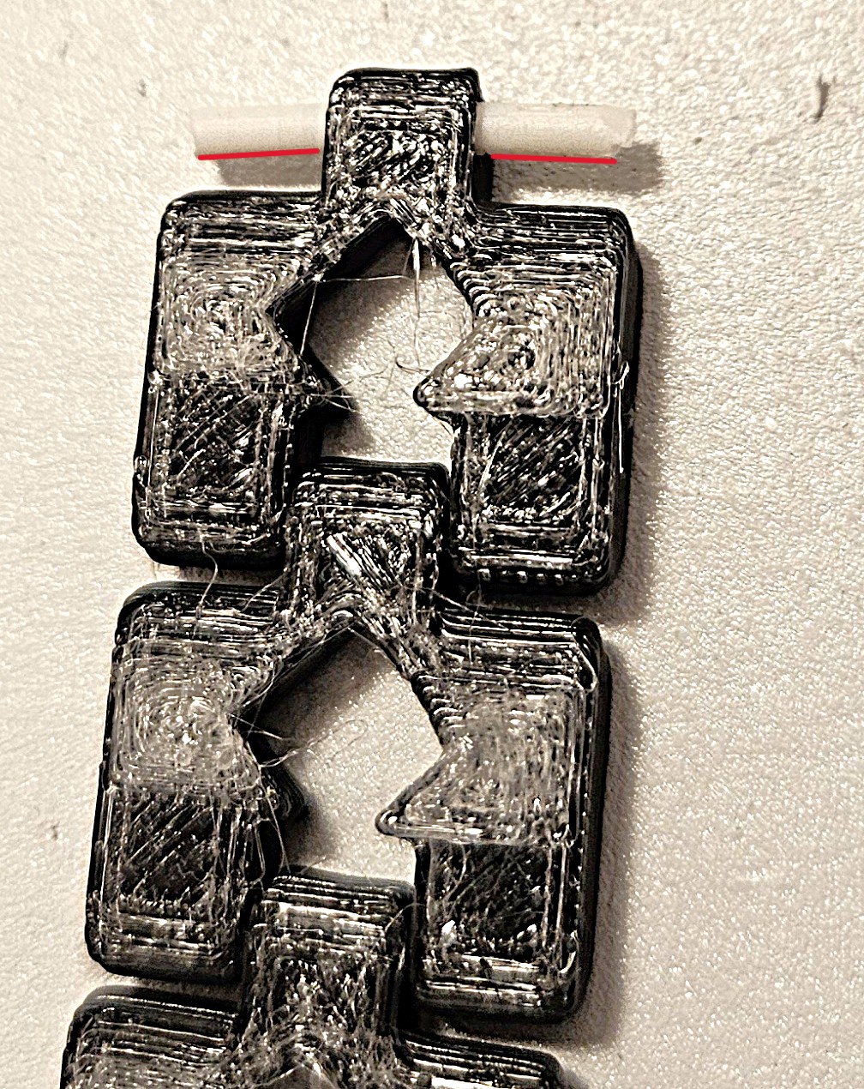
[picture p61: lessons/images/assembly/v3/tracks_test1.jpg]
Track Pieces Testing


Do the end with two holes as well.

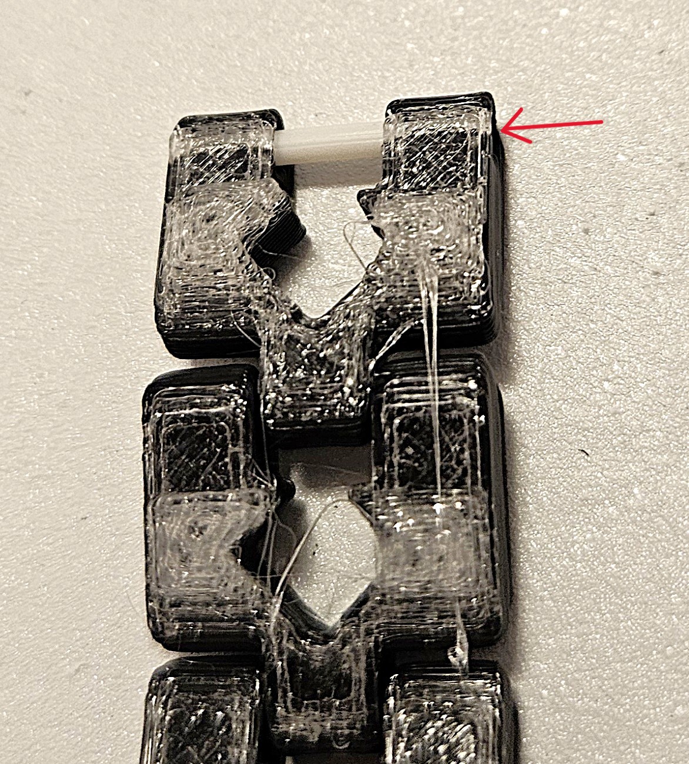
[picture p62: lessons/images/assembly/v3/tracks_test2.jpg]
Track Pieces Testing two hole end


**NOTE:** Be sure to **remove** the filament before proceeding.

Take one track at a time and wrap it around the wheels BEFORE connecting with the filament. It's recommended to have the end of one track rest on top of one wheel with the other end just below it as you see in the picture below:

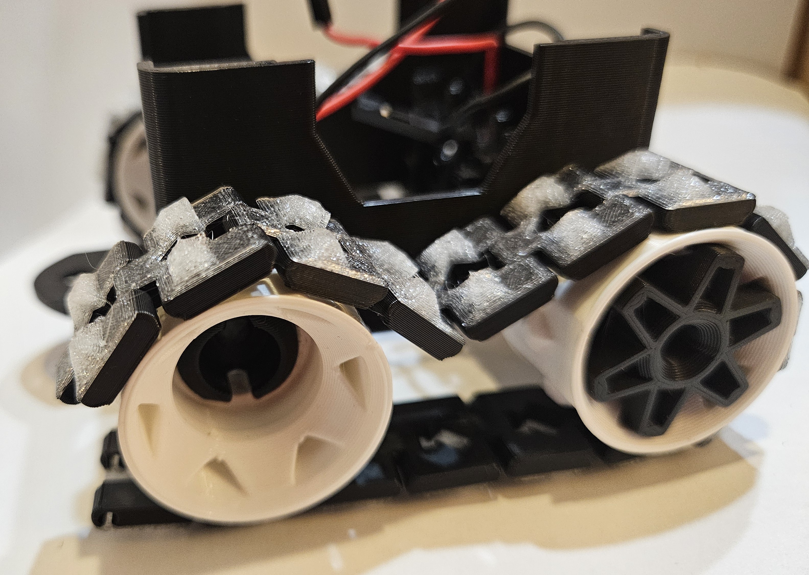
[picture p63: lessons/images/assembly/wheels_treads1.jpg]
Track Pieces Wrapped


Now align the two ends of the track and insert a piece of filament through the hole to connect them as seen in the picture below:

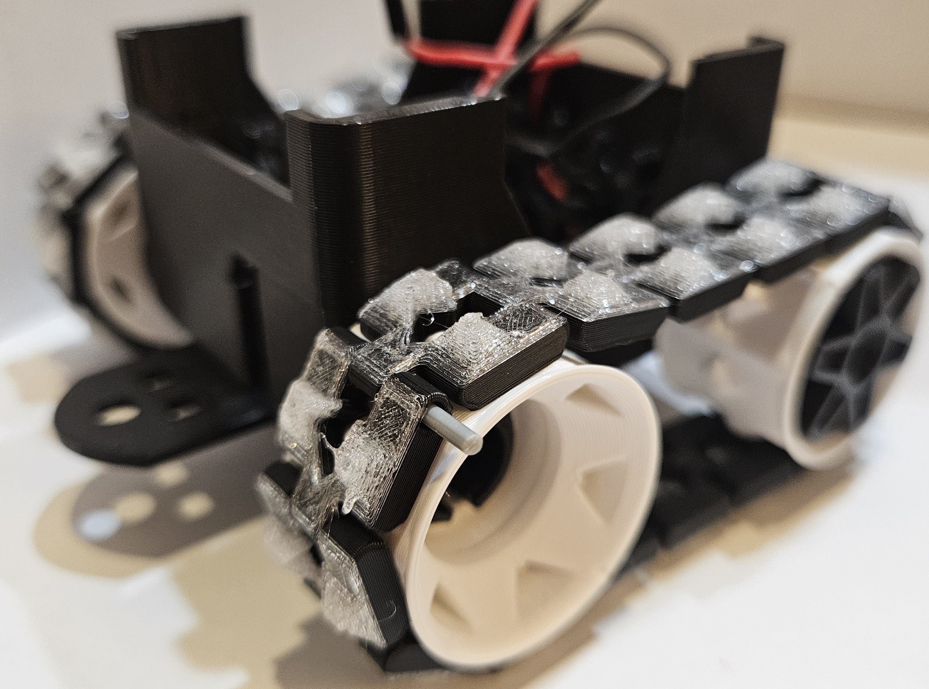
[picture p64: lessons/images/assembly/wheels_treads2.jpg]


If you struggle getting enough slack in the tracks to get the ends to line up to insert the filament, try rotating the wheels a little back and forth until the tracks lay with their notched hole over the diamond tabs on the surface of the wheels. With a little sliding of the tracks and rotating of the wheels, you should be able to easily line up the ends of the tracks to connect them.  

Once the ends are aligned, push the filament through till its flush with the inner most piece of the track closest to the chassis.  Once connected you can cut the filament off to be as flush as possible, but if it sticks out a little it should be fine as long as it's not protruding too much on the inside where it might rub on the chassis as the treads move around the wheels. 

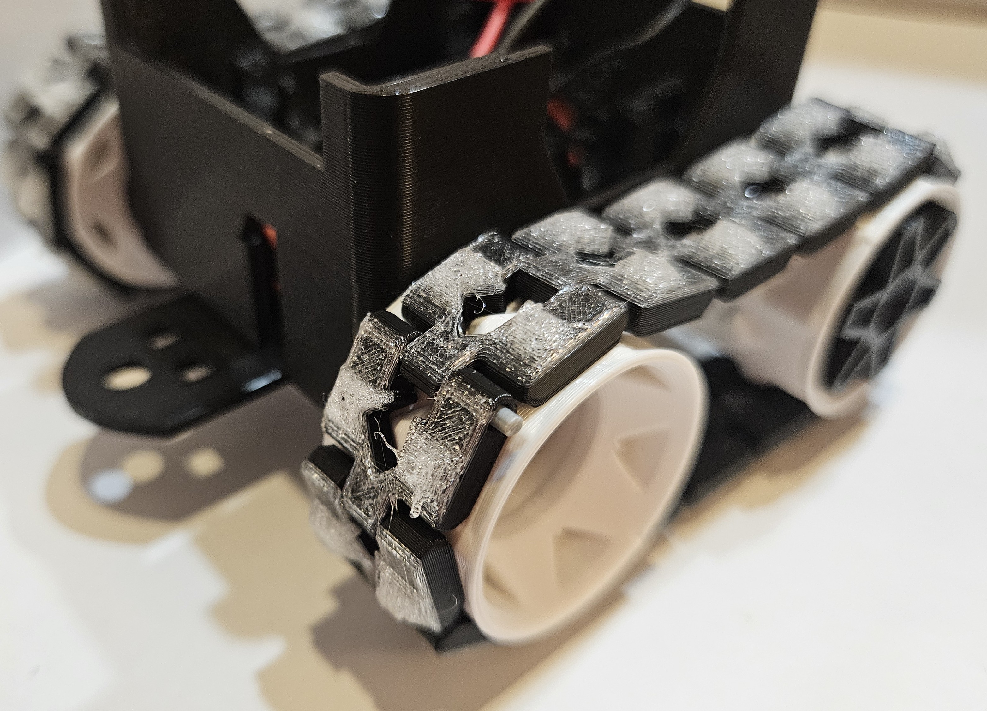
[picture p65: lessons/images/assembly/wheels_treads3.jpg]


Repeat these instructions to assemble the second track.

Jump around and celebrate!

[back](https://github.com/javaplus/MadScientist/blob/main/lessons/assembly/chassis.md)

[next](https://github.com/javaplus/MadScientist/blob/main/lessons/assembly/power.md)

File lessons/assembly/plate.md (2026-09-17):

# Pico Plate & Motor Controller

## Parts

- Pico WH  
- 4 x 10cm female to female wires (recommend a combination of blue, yellow, white, and green)

***Pico WH and wires(Note colors may be different than pictured)**
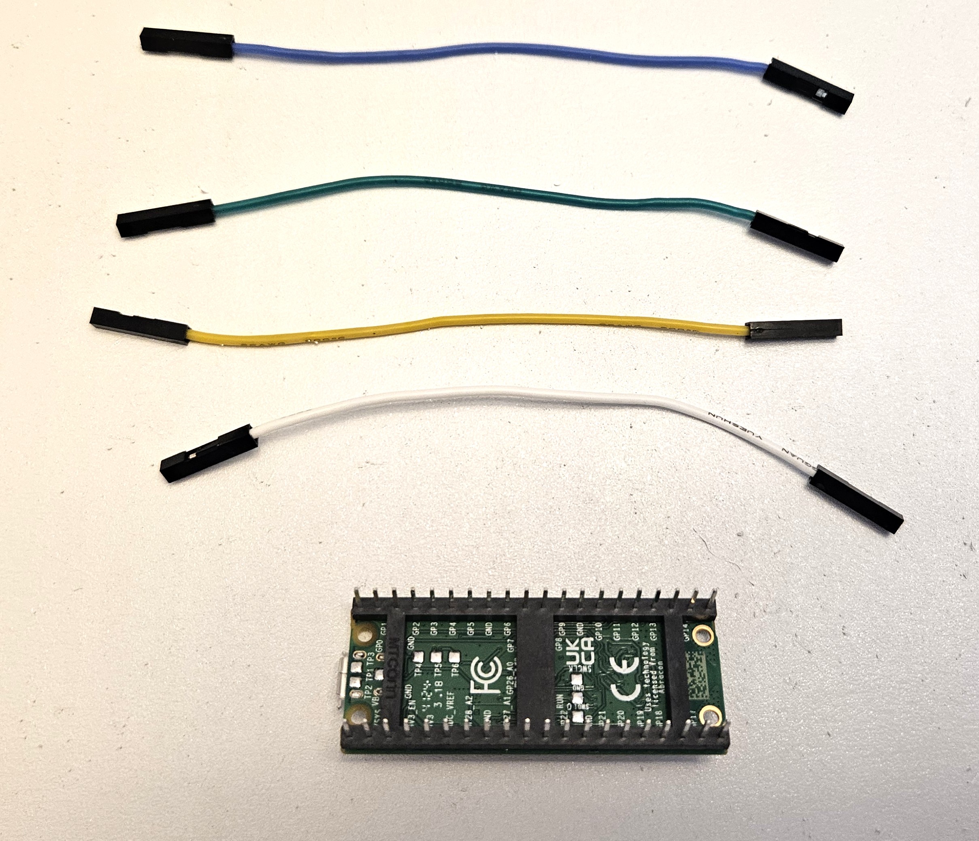
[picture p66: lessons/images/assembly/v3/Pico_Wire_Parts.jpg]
Pico Plate Parts


## Prepare Pico Wires for Motor Controller

We are now going to connect our 4 wires to the Pico that will eventually connect to the motor controller that will allow the Pico to control our motors.

Your 4 wires will go on the GPIO pins GP10, GP11, GP12, and GP13.
<details>
	<summary>More Details</summary>

	The exact color of the wires doesn't matter, but it may be easier to follow the pictures. The wires go together in pairs to control the 2 motors. The GP10 and 11 pins control one motor by going to the Motor Controller's INT3 and INT4. While the GP12 and 13 pins on the Pico need to connect to the INT1 and INT2 pins. 

</details>

Take your 4 wires and connect them to the Pico as indicated in the picture below.

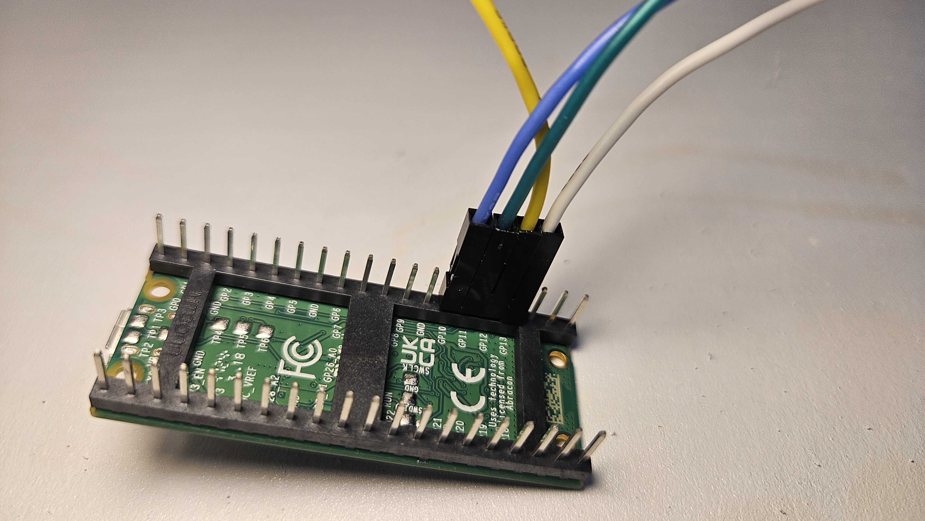
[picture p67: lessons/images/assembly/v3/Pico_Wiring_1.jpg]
Pico wires for Motor Controller


Now your Pico wires are ready to connect to the motor controller, but let's mount the motor controller to the plate first.

## Motor Controller Install

### Parts
Grab the Pico plate (the flattish square piece) and your motor controller.

Orient the plate so that the square is in the bottom left as seen below.

Pico Plate and Motor Controller parts

### Mount the Motor Controller

Take the motor controller and put it into the bottom left square on the Pico plate so that the 4 pins on the left side of the motor controller go through the slot on the left of the recessed square.  The 6 pins of the motor controller should be facing up and on the right side of the recessed square. To snap the motor controller in the recessed slot, align the downward 4 pins through the hole, and then angle the motor controller so that the side opposite the capacitors (the round silver things) goes in the recess first. Then the side with the capacitors; which are closest to the bottom edge and closest to you in the picture, will go in last.

Motor Controller angled

Using your thumbs on top of the capacitors, snap the motor controller securely into the recessed square. It will take a little force, but you should be able to feel a satisfying snap when it goes in place.

Motor Controller Snap with thumbs

The top of the red part of the motor controller should be slightly lower than the top surface of the Pico plate when fully snapped in place as seen in the picture below.

Motor Controller In Place

## Wire Pico and Motor Controller

Now take the Pico with the 4 connected wires and place beside the Pico plate to left of the motor controller.  At this time, do not place the Pico on the Pico plate, but just beside it so the wired side of the Pico is next to the motor controller so you can easily connect the wires to the motor controller.  Now connect the wires from the Pico to the motor controller as seen in the picture below with the GP10 and GP11 pins(Blue and Green wires in the picture) on the Pico connected to the INT 4 and INT 3 connections on the motor controller. Then connect the GP12 and GP13 pins(Yellow and White) of the Pico to the INT 2 and INT 1 of the motor controller. See the pictures below for the correct wiring.

|  Pico pin | Motor controller pin| Color  |
|---|---|---|
| GP10 | INT 4 | Blue |
| GP11 | INT 3 | Green  |
| GP12 | INT 2 | Yellow |
| GP13 | INT 1 | White  |

Pico and Plate Parts

Pico and Plate Parts

### Mount the Pico on the Pico Plate

Now find your 4 pico pins to mount your Pico to the plate. (**NOTE**: Your pins may be a different color than those in the picture below.)

Pico and Plate Parts

Now pick up the Pico and move it over the motor controller so the wires tuck below the Pico as seen below:

Mounting Pico to the Plate part 1
Mounting Pico to the Plate part 2

Now position the Pico, with the wires underneath, so that the 4 holes on the Pico line up with the 4 raised posts on the Pico Plate.  Now insert your pins through the holes to secure the Pico in place.  Try to push the pins all the way down, but don't use too much force and it's ok if the Pico has a little play with it.  As long as the Pico doesn't easily come off the Pico plate, you should be good. In a pinch, using 2 in opposite corners will work. 

Mounting Pico to the Plate with pins

Mounting Pico to the Plate with pins

[next](https://github.com/javaplus/MadScientist/blob/main/lessons/assembly/chassis.md)

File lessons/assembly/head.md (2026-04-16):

# UA Hackathon Participants: Skip to Old Head instructions using Link Below:
[Old Head Instructions](/lessons/assembly/head_old.md)

# Head Assembly Instructions
## Parts List

Before beginning the assembly, ensure you have the following four printed parts and electronics ready:

* **Head Top:** 3D printed part with the top of the head and eyes already pre-assembled.
* **Chin Piece:** Includes two upward-facing tabs/slots.
* **Teeth & Gums:** 3D printed part featuring a laser slot and alignment slots.
* **LED Harness:** Pre-loaded with LEDs and wiring — see the [LED harness assembly](rgb.md) for harness assembly instructions.
* **Laser Module**

Jaw Components

---

## Assembly Steps

### 1. Electronics Preparation & Jaw Sub-Assembly
First, prepare the jaw unit before placing it on the rover:
* **Laser:** Insert the **Laser Module** into the center-front slot of the **Teeth & Gums** piece.
* **Chin:** Take the **Chin Piece** and slide it up from underneath the **Teeth & Gums** piece.
    * The chin slides into the single long slot at the far back of the gum piece.
    * Ensure the two tabs from the chin protrude upward through the slot.

Laser Insertion
Chin Assembly
*Visual Check: The Laser is seated flush, and the Chin is firmly slotted into the Gums.*

### 2. Mount Jaw to Rover Body
Now that the Chin and Gums are assembled (with the laser inside), place this unit onto the rover body.
* Position the sub-assembly onto the front of the chassis.
* Ensure it is seated correctly before proceeding to the wiring steps.

Chin Side View
*Visual: The Jaw unit sitting in place on the rover chassis.*

### 3. Insert the LED Harness
With the jaw unit now mounted on the rover:
* **Wire Management:** Move the laser wires to the side to ensure they do not obstruct the harness path.
* **Alignment:** Locate the long slot in the middle of the **LED Harness**. This slot must slide *between* the two tabs from the Chin piece (which are sticking up through the gums).
* **Orientation:** Confirm the wire order matches the harness assembly (Red, Black, Green, Blue) and orient the harness so wires exit toward the rear.
* **Insertion:** Slide the LED harness down into the long slot.
* **Safety Check:** Verify that no wires are pinched during this process.

Placing Harness
Harness Set
*Visual: Top-down view showing the LED harness sliding between the chin tabs while on the rover.*

### 4. Final Connection
* **Connect the Laser and LED wires according to the Wiring Table below.** See the [LED harness assembly](rgb.md) for harness assembly details.

> **Note:** The head assembly can be installed **prior** to attaching the middle cap.

**Wiring (canonical)**

- **LED Harness** (female ends to Pico):
  - RED   -> **GP22**
  - BLACK -> **GND**
  - GREEN -> **GP21**
  - BLUE  -> **GP20**

- **Laser Module** (signal/pwm):
  - SIGNAL -> **GP16** (Red Wire)
  - GND    -> **GND** (Blue Wire)
  - **Software note:** the laser is instantiated on pin 16 in `code/main.py` (e.g., `Laser(16)`).

> **Safety:** Do not point the laser at people, animals, or reflective surfaces. Use brief test pulses only.

**Testing the harness**
1. Run the simple LED blink example from the [LED lesson](../Led.md) to verify colors/pins.
2. Use `laser.fire(1)` from `code/laser.py` to briefly test the laser.
### 5. Test and Put On Body

After connecting the laserl and RGB, it may be a good idea to test functionality before you put the final 3D printed pieces of the shark on.
Test that the laser lights up when you press the "fire" button and the RGB lights flash when turning it on.  This assumes you have the code installed from the previous steps. - [Install Shark Code](/lessons/assembly/code_install.md)   

Once everything is working, now put the shark body on the mid section.  That is the part with the fins. It Be sure not to pinch any wires and ensure that the bottom of the body is flush with the pico plate.

### 6. Attach the Head Top
To finalize the head assembly:
1.  **Route Wires:** Position your wires out of the way to ensure a clean fit.
2.  **Front Alignment:** Locate the small lip under the nose of the **Head Top** piece. Catch this lip on the overhang located directly above the laser slot (between the front two teeth of the gum piece).
3.  **Rotate & Lock:** Once the nose is caught, rotate the bottom-back of the head down into the gums.
    * The head should line up with the two small slots on the gum piece.
4.  **Snap Fit:** Press down until you hear a satisfying snap, ensuring the assembly is secure.

Head Alignment on Lip
Head Lowering
*Visual: The "Catch and Rotate" motion to attach the head.*

Head In Place
*Visual: The fully assembled head unit mounted and ready.*

### Finito!

Congratulations! You've finished the Shark Rover... now it's time to try it out in its full glory.
You probably already have the code installed and the mobile app, but if you don't install them now:

- [Install Shark Code](/lessons/assembly/code_install.md)  
- [Mobile app](https://github.com/javaplus/mad_scientist_app/blob/main/README.md)

After installing the code on the shark and getting the mobile app controls, take your shark on an adventure!
Turning the shark on, should cause the RGB LEDS to blink blue showing that it is trying to pair via bluetooth with the mobile app.  
In the mobile app, your shark name should show up in the list (You did remember to change the line of code to put your [unique shark name](https://github.com/javaplus/MadScientist/blob/main/lessons/assembly/code_install.md#main) in there didn't you?? ).
When you see your shark name in the list, click `connect` and then your shark's eyes should turn green showing its connected.  Now you are ready to drive!

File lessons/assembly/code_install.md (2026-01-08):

# Install the Code

Open up Thonny and make sure the **rover is turned off**.  Always be sure to have the battery power off to the Pico before plugging in the USB cable.

Once the rover is switched off, plug in the USB cable.  If Thonny doesn't recognize the Pico, try hitting the STOP button.  If that doesn't work try clicking the bottom right to choose the correct device : MicroPython(Raspberry Pi Pico).

### Clone this repo!

Clone the repo [MadScientist](https://www.github.com/javaplus/MadScientist) locally.

### Use Thonny to load files to pico

Once you have the repo cloned, open Thonny and if you don't have the files tab already opened, navigate to View -> Files.

This will open a navigation pane where you can select files to transfer.

animation of the view files action on thonny  

Navigate to where you cloned the repo and select all of the '.py' files under the 'code' directory.  Right click on one of the selected files.  Select "Upload to /".  You should see all of the appropriate files transfer.

animation of upload steps on thonny  

#### Main

Open main.py on your Pico using Thonny via the File -> Open menu and selecting on your Pico on the prompt.

Find and change the value of the `ROVER_NAME` variable to be something unique.  This will be the Bluetooth device name of your Rover.  Change this to something you can easily remember and unique if doing this with a large group of others.
Below is the code you need to change... change the "Put Your Unique Groovy Shark Name Here" value to your special name:
```Python

# ROVER_NAME needs to be a unique name for your rover.  It will be the Bluetooth device name
ROVER_NAME = "Put Your Unique Groovy Shark Name Here"

```
After changing the ROVER_NAME value, save the code to the Pico. 

**Fun Fact**: any code you save into `main.py` at the root of the Pico will run automatically when it's powered up.

####  Try It Out!

After saving all these files to the Pico, make sure to have the `main.py` window up in Thonny and click the "Run" button.  See if there are any errors in the shell.
If you see an error about a **picozero** library or module, be sure to follow these steps to [install picozero onto the Pico](https://picozero.readthedocs.io/en/latest/gettingstarted.html#install-picozero-from-pypi-in-thonny).

If there are no errors, it's time to test it out!

Since testing it out means using the [mad scientist app](https://github.com/javaplus/mad_scientist_app/blob/main/README.md) to control the motors, you may want to lift the Rover off the ground while connected to the USB cable.  You can use one of the included clear dixie cups upside down under the Rover to keep the tracks off the ground.

Rover Lift
Now open the mad scientist app and connect to the Rover.  Be sure to keep the power switch off on the Rover.  

When the RGB eyes are flashing blue, that means the rover is advertising and waiting for a Bluetooth connection.  
In the mad scientist app, type in the value you put for the `ROVER_NAME` variable to make it easier to find your rover and then hit `CONNECT`.

When the app is connected to the Rover, if you've installed the shark, the eyes should turn green.  Now try to move the joystick in the app to test the motor control is working.  If any of the movement is reversed, you can simply go to the settings menu of the app and reverse the controls.

#### Issues With Motor Directions
Even if you connected the wires correctly for the motors, because you can't tell which direction a motor will spin until it has power, your motors may spin in different directions than you expected.

1. If the directions are simply inversed (eg, the rover moves forward when you go backward, or turns left when you turn right) then you can select the "cog" icon in the upper-right of the app, and choose to invert the forward direction and/or the turning direcion
2. If when testing forward and backward, the wheels spin in opposite directions, you will need to modify some code in _motor_class.py_. Starting at line 17, flip the pin numbers for either the _left_motor\_\*_ or _right_motor\_\*_
  So if the left motor is spinning the wrong direction, change lines 17-18 from this:
    ``` Python
    self.left_motor_forward = PWM(Pin(10))
    self.left_motor_backward = PWM(Pin(11))
    ```
    To this:
    ``` Python
    self.left_motor_forward = PWM(Pin(11))
    self.left_motor_backward = PWM(Pin(10))
    ```

#### FREEDOM!!!

If everything tests out ok while connected via the USB cable, it's time to unplug the USB cable and set it free.  Place the Rover on the ground and turn the power switch on.  The eyes should flash blue again, showing that it's advertising and ready to connect.  Use the app again to connect and try it out!!!

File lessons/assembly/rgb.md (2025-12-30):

# LED Harness Assembly

## Parts Required

* **2x RGB LEDs (5mm):** These must be **Common Cathode** (where the long pin is Ground).
* **4x DuPont Wires (Female-to-Female):** Prepared to receive the LED pins.
* **Printed Harness Shell:** Two halves that snap together (part of the `head_parts` print).

RGB and Harness Parts
*Visual: The disassembled harness shell, LEDs, and wires.*

---

## Assembly Steps

### 1. Identify LED Pinout
Before connecting anything, identify the pins on your RGB LEDs.
* The **Longest Pin** is the **Common Ground (Cathode)**.
* When holding the LED so the pins point down and the flat side of the lens is to the left, the order is generally: **Red, Common (Ground), Green, Blue**.

> **Note:** We are using **Common Cathode** LEDs. If you wire this up and the colors are inverted or don't work, verify your LED type.

### 2. Connect the Wires
We need to connect both LEDs to the same four wires (Parallel connection) so they light up in unison.

Make sure the slot order (left-to-right) matches: **red**, **black (ground)**, **green**, **blue**.

1.  **Group the Pins:** Align the two LEDs so their pins match (Red to Red, Ground to Ground, etc.).
2.  **Insert into Connectors:** Insert the corresponding pin pairs into the female ends of the DuPont wires.
    * All **Red** pins -> Red Wire
    * All **Ground** pins -> Black Wire
    * All **Green** pins -> Green Wire
    * All **Blue** pins -> Blue Wire
3.  *Tip:* Ensure the connection is snug. If using a specific connector housing (like in the image), push the pins in until they lock.

Connecting Pins
Wires Connected
Wires Connected 2

### 3. Seat in the Harness
1.  **Align the Junctions:** Take the lower half of the 3D printed harness.
2.  **Place the Wires:** Lay the metal connection points (where the LED pins enter the DuPont connectors) into the four grooves inside the harness shell.
    * The plastic housing of the DuPont wire should sit just outside or flush with the internal stops.
    * The LED bulbs should be sticking out of the front.

Seating the Wires

### 4. Close the Assembly
1.  **Snap Shut:** Take the top half of the harness shell and press it down onto the bottom half.
2.  **Secure:** Squeeze firmly until the harness snaps shut, locking the wires in place.

Final Adjustment
*Visual: The completed harness with LEDs angled for the eyes.*

### 5. Final Adjustment
1.  **Bend the LEDs:** Gently pull the two LEDs slightly apart and angle them outward.
2.  **Aim:** The goal is to angle them so that when the harness is inserted into the shark head, the lights shine directly into the eye sockets.

---

## Wiring to Pico

Now connect the female end of the wires to the Pico.

**Wiring (canonical for the head harness):** RED -> **GP22**, BLACK -> **GND**, GREEN -> **GP21**, BLUE -> **GP20**. See the image below which is a zoomed in view of the [overall wiring diagram](../images/overall_layout.PNG).

> **Note:** These mappings are the canonical head wiring — see the [Head assembly](head.md) for the head installation and final wiring table.

**Next Step:** Proceed to [Head Assembly](head.md) to install this harness into the rover.

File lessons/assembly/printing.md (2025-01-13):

# Printing Instructions

## Head

Parts for Head

Orientation of print can match that of how the items are on the photo above.  The head should be printed with added organic supports to support the low points of the top gumline.  See image for example:

organic supports for the head

The head/"noggin" should be printed in 10% infill.

The rest of the parts relating the head can be printed at 100% infill.  No brim.  No supports.

The teeth can have the pre-added supports removed like in the image below.

removing teeth supports

The following image shows the correct way to install the right eye. You might notice a small amount of extra material on the eye in the picture. This is from the 3D printing process and could prevent the eye from snapping into place. Be sure to remove any excess materials from the eyes leftover from the printing process as it will make the installation process more difficult or impossible.

right eye details

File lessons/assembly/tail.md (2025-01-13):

# Tail Assembly with Photoresistor

### Parts

- Tail
- Opaque tail tip
- Photoresistor

Parts for Tail

The instructions for this part were hard to put into words... Actually, my reviewers told me I sucked at it, so here's a video of this assembly since the written instructions may not be clear:

### Video
[Tail Assembly Video](https://youtu.be/BuBBeq6uPUs)

Written instructions below:

### Insert Photoresistor

Position the tail tip upside down (flat side facing up).
Take your photoresistor and carefully slide it into the slot in the tail tip.  Then take the photoresistor tip and put it **under** the uppermost bar.  Turn the photoresistor so the two metal pins are vertical and align the bottom pin with the slot in the tail tip.  See image below:

Tail Tip Photoresistor 1

Now by pushing on the tip of the photoresistor, force it down into the tail tip while having the two wires got into the T-shaped slot.  To make it easier to align the pins with the slot, you may bend the wires a bit at an angle to make it easier for you.

Tail Tip Photoresistor 2

Tail Tip Photoresistor 3

Slide the photoresistor pins all the way down the T-shaped slot to the horizontal slot and rotate it 90 degrees so that the two pins straddle the vertical slot the pins just came through.  Flip the tail tip over, so the flat spot is on facing down.  You should see two small slots on each side of the vertical slot that your pins should rest in when they straddle the vertical slot.  NOTE: In the next few steps as you attach the tail tip to the tail, the photoresistor pins may shift in positions. This is ok, but the picture below shows the correct orientation the photoresistor should be in later when you attach it to the tail.  So, try to position it correctly now, but it will most likely jostle out of position as you continue and that's ok.  We will correct it later.

Tail Tip Photoresistor 4

Tail Tip Photoresistor 5

### Route the Wires

Now, route the end of photoresistor wires through the tail.  From the picture below, you can see the correct hole to put the wires through is the middle hole when the tail is upside down.  Try to keep the blue and black wires together on one side of the shaft and the red wire on the other side of the shaft inside the tail.  It doesn't matter which wires go on which side, the goal is not to twist the photoresistor pins and to keep them separated.  If the photoresistor pins are allowed to touch, it will not work properly.  It won't hurt anything, but just will not function as expected.

Tail Wires

Tail Wires 2

Tail Wires 3

### Add the Tail Tip

Now carefully snap the tail tip onto the tail. To do this, hold the tail upside down and the tip up away from you so you can see the hole with the wires.  Hold the tail tip up with the tip pointing upward and the flat piece towards you as in the picture below.  Slide the tail tip down into the hole you previously routed the wires through.  At this point before you fully snap the tail tip in place, adjust the metal pins of the photoresistor into the two cutouts beside the vertical T-shaped slot.  When you snap the tail tip into place the photoresistor tip should be pushed slightly in and just beyond the crossbar in the tail.  This bar will also lock the photoresistor in place. Snap the tail tip in place now.

Tail Tip Add
Tail Tip Add 2

Once the tail is snapped in, pull the photoresistor back in a little until it is just behind the bar in the tail. We find this position gives the best detection of laser hits on the tail.

Tail Tip Add 3

Once the tail tip is snapped in you are done with the tail assembly!  Rejoice!!!!

Tail Complete

[back](https://github.com/javaplus/MadScientist/blob/main/lessons/assembly/plate_chassis.md)

[next](https://github.com/javaplus/MadScientist/blob/main/lessons/assembly/tail_chassis.md)

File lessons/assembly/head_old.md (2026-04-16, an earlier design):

# Head Assembly with Eyes, LEDS, and sharp teeth! - oh my!

## Parts

- Noggin (head)
- Pearly White Teeth
- Laser with attached female dupont ends
- Front Cap Connector
- LED Harness Assembly
- Left Eye
- Not Left Eye (Right Eye)
- 2 RGB LEDs
- 4 Female/Female wires: selecting a combination of red, green, and blue (and any other color) wires will result in slightly easier wiring later.

## Harness the power of LEDs!

Grab your harness and place it in the back section of the head at a 90 degree angle with the "key" portion of the harness pointing towards the right eye.

ninety degree harness install step one

The key should slot down into the center piece of the back framing portion of the head.

ninety degree harness install step two

You can see in the image above how the tab barely sticks out of the center area.  Center the harness as best you can.

LED harness centered

Grab the front cap connector piece.

With your rover's head upside down, begin to slot the cap connector in place with the thicker tab on the side of the left eye.

There are a number of tabs that slot into each other with this step so be careful not to force anything if it doesn't glide smoothly.

front cap connector install

Once you have fully slotted the front cap connector into place and appropriately centered the LED harness into place, you can do a final adjustment of the LEDs to point towards the eyes, and you will have your completed head unit!

completed head unit

Slot your head into place onto the front of the chassis!  Don't pinch any wires!

Refer to the following photo for how to wire your head's components to the board.

| LED wire color | Pico pin |
|---|---|
| Red LED wire | GP22 |
| Ground LED wire | GND |
| Green LED wire | GP21 | 
| Blue **LED** wire | GP20 |
| Blue **laser** wire | GP16 |

the head is on the chassis

## CAP it all off!

Make sure that no wires are in the way of any pinch points and slot your middle cap piece into position.
It will secure nicely to the head and tail pieces as seen in the clip below.

capping it all

### CONGRATULATIONS!  You have completed your shark ROVER assembly.

Happy Hunting.

[back](https://github.com/javaplus/MadScientist/blob/main/lessons/assembly/tail_chassis.md)

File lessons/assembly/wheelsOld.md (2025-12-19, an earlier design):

# Wheels and Tracks

### Wheels and Tranny

### Parts

- 4 wheels
- 2 transmission pieces

Wheels and Tranny

Now let's install the wheels.  

Take your 4 wheels and snap them on the chassis.  Make sure the flat side is against the chassis.  Once they snap on, give them a spin with your hand to make sure they can spin freely without much resistance. 

Wheels installed 2

Now install the 2 transmission pieces.  The axles have a D shape.  The tranny parts have a D shaped slot in the center.  Match the holes to put the tranny onto the axle.  
The easiest way to do this is to start inserting the tranny piece into the wheel until it hits the axle while holding the motor from sliding back.  Then rotate the wheel and the tranny till the D shaped hole and the axle line up and you can push the tranny in flush with the outside of the wheel.

Tranny installed

### Tracks

### Parts
- Track pieces (2 packs of 16 track pieces per container)
- 3D printer filament

Track Pieces

Take two pieces of track at a time and insert a piece of filament through the hold to connect them as seen in the picture below

Track Pieces Connect 1

Track Pieces Connect 2

Cut the excess filament off to be as flush as possible. If you have a little filament sticking out on each side, it should still be fine, but flush is better.

Track Pieces Cut

From this point just grab another track piece and add it to your existing connected track pieces and keep connecting until you get 16 of them connected in a line.

Track Pieces 16

Now circle the track around and connect the two ends to make a fully connected track:

Track connected

Repeat these instructions to assemble the second track.

Once both tracks are complete, simply put the tracks on the wheels. Just slip the track partially over one wheel and then stretch it back to wrap around the other wheel.  The track pieces are printed with TPU and should have a little flex, but you could deform the filament holding the track pieces together if you stretch it too much.

Tracks on Chassis  
Tracks on Chassis 2

Jump around and celebrate!

[back](https://github.com/javaplus/MadScientist/blob/main/lessons/assembly/chassis.md)

[next](https://github.com/javaplus/MadScientist/blob/main/lessons/assembly/power.md)

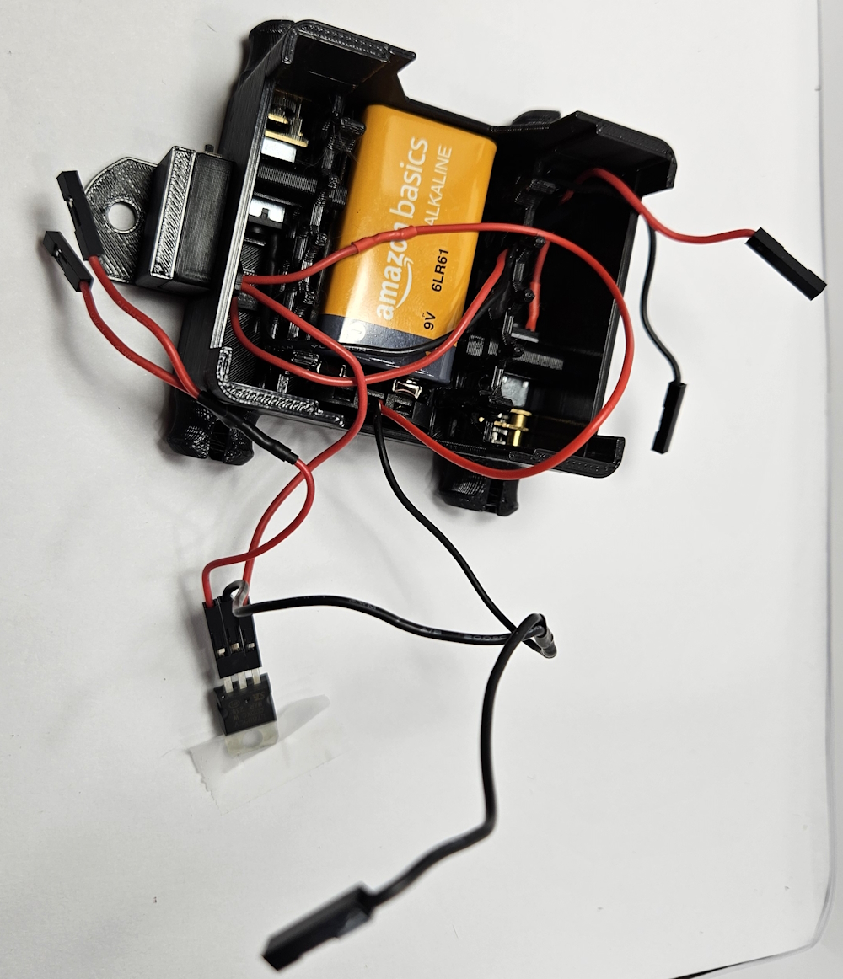
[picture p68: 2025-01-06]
lessons/images/assembly/power_regulator_power_switch_2.jpg

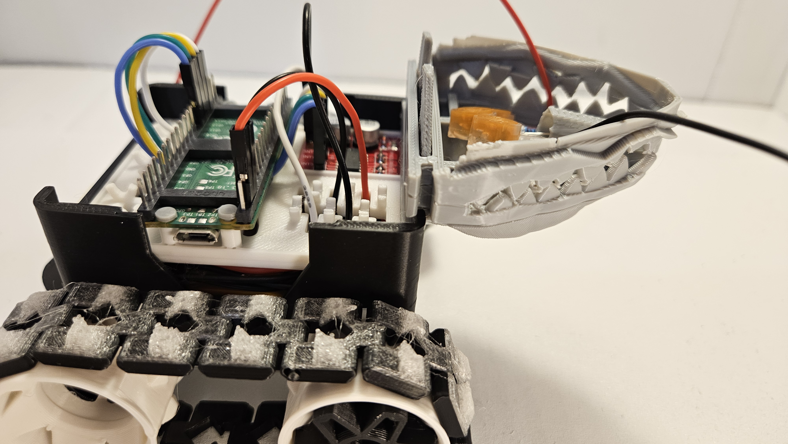
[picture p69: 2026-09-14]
lessons/images/assembly/v3/ChinJawInstall.jpg.jpg

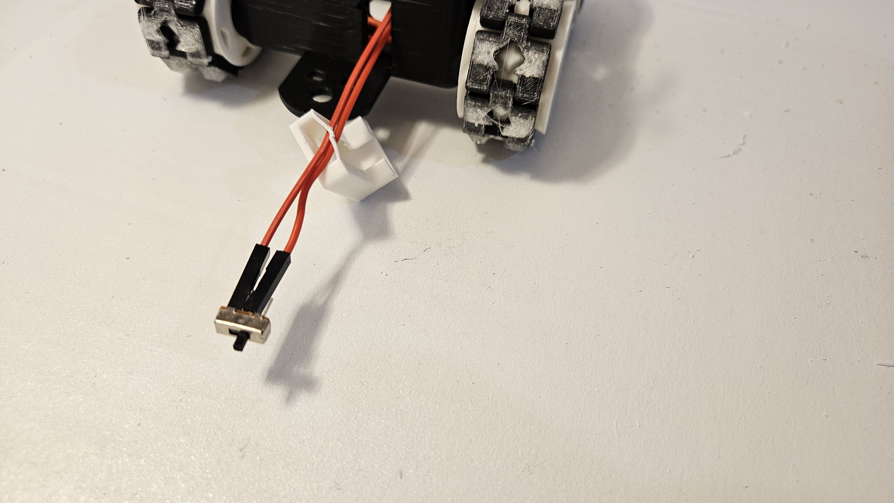
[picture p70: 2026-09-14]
lessons/images/assembly/v3/PowerSwitchInstallChassis6.jpg

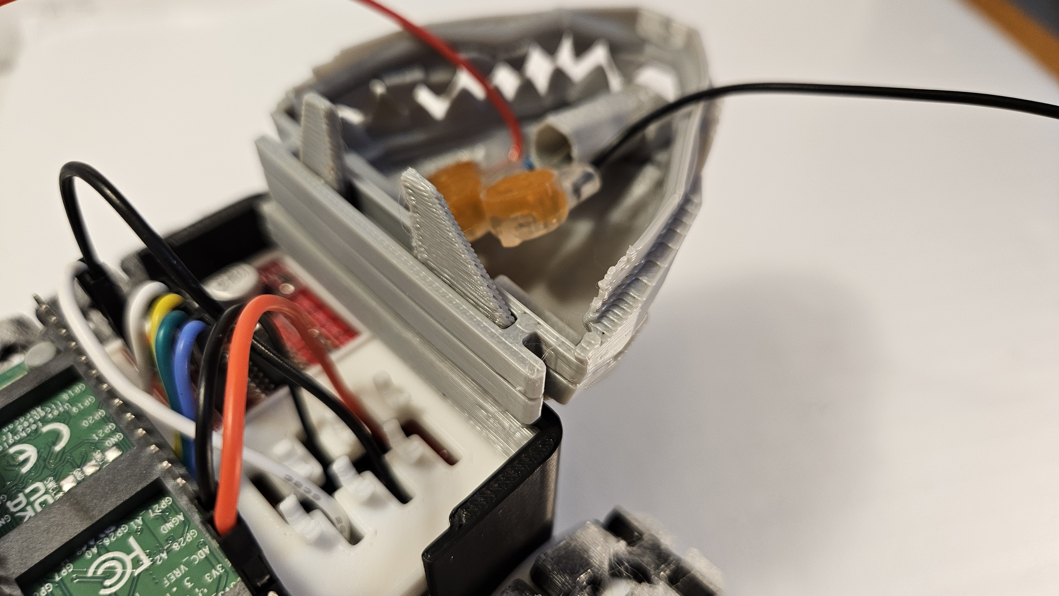
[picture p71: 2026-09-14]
lessons/images/assembly/v3/ChinJawInstall2.jpg

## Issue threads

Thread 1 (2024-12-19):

Create Motor Tutorial between simple and using motor controller

javaplus, 2024-12-19:
There  are currently two tutorials for working with motors the basic one is [here](https://github.com/javaplus/MadScientist/blob/main/lessons/SimpleMotor.md) and just covers an intro to DC motors and how to use the Pico as a  battery to make it turn on.

The more advanced tutorial is around using the [motor controller](https://github.com/javaplus/MadScientist/blob/main/lessons/MotorController.md) and is more like you'll  actually use the motor in the final assembly.

However, what I feel is missing is something in between.
I'd like a new lesson to fit in between these that shows how to connect the motor directly to a GPIO pin and ground and then use code to turn the motor on and off.  And then a second part to that same lesson would be to use PWM to control the motor speed of the motor.  Then point out at the end that we can control the motor speed with code, but not direction  and that would be a great lead in to the existing motor controller lesson... which is one of  the reasons why we use a motor controller to control speed and direction.

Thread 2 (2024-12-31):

Game mode implementation

barthba, 2024-12-31:
from barry:

If you get hit, the rover does almost a complete 360 spin in place before being able to move again
There's a been_hit() function that controls what happens when you are hit... we may want different implementations depending on the game mode... someone want to look into that?
Could use help either making an easy way to swap out implementations based on some global game mode variable or just coding other fun things to happen when you get hit.

bb notes:

here are the modes we discussed before:

Mode Descriptions:

**Hungry Games**

In this thrilling every-shark-for-themselves mode, all players start with a cool blue glow. But beware! One wrong move and you'll be tagged, triggering a dramatic stop-motion freeze as your lights turn a menacing red. You're out of the game, but the action continues! The last shark swimming with their blue light shining emerges as the ultimate predator.

**Sharkbyte**

A contagious frenzy takes over the arena! One player starts infected with the Sharkbyte virus, glowing a sickly green. Their mission? Spread the infection! Every shark they tag joins the horde, turning green and helping to spread the virus.  Uninfected players (glowing blue) must use their agility and cunning to avoid the infected and survive until the timer runs out.

**Optional Twist:** To increase the challenge, infected players could be slowed down, making it harder for them to catch their prey and spread the virus. This adds an extra layer of strategy and suspense to the game!

**Saturday Bite Fever**

Get ready to boogie! In this high-energy mode, getting tagged triggers a dazzling disco fever. Your shark will go into a spinning frenzy while your RGB lights erupt in a vibrant rave show. It's a party in the laser tag arena, even if you're temporarily out of the action.  This mode adds a fun and exciting element to the game, encouraging players to embrace the chaos and enjoy the light show!

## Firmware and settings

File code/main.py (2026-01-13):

import aioble
import bluetooth
import asyncio
import struct
from sys import exit
import utime
from picozero import RGBLED
from machine import Pin, PWM, ADC
from hitevent import HitEvent
# Import the MotorController class
from motor_class import MotorController
from basicgame import BasicGame
from virusgame import VirusGame
from discogame import DiscoGame
from wtfgame import WTFGame
from buzzer import Buzzer
from fireevent import FireEvent
from laser import Laser
from drivegame import DriveGame


laser = Laser(16)
photoresistor = ADC(28)
photoresistor_value = 0
## When calibrating what is the baseline
photoresistor_baseline_value = 0
photoresistor_hit_value = 28000
PHOTORES_HIT_FACTOR = 1.00
# After being hit you are immune for 2 seconds
HIT_DEBOUNCE_TIME = 2000

saved_sensitivity = 5

# RGB  status lights for indicating advertising, connected, and commands recieved.
rgb = RGBLED(red = 22, green = 21, blue = 20)

# ROVER_NAME needs to be a unique name for your rover.  It will be the advertised bluetooth device name
ROVER_NAME = "Put Your Unique Groovy Shark Name Here"

# Bluetooth parameters
BLE_NAME = f"{ROVER_NAME}"  # You can dynamically change this if you want unique names
BLE_SVC_UUID = bluetooth.UUID(0x181A)  # Environmental Sensing Service
BLE_CHARACTERISTIC_UUID = bluetooth.UUID(0x2A6E)  # Temperature
BLE_APPEARANCE = 0x0300  # Thermometer
BLE_ADVERTISING_INTERVAL = 2000

# Buzzer on pin 15
buzzer = Buzzer(15)

# Instantiate the motor controller
motor_controller = MotorController()

# Instantiate the HitEvent so it can be fired when hit:
hitevent = HitEvent()

# Instantiate the FireEvent so it can be emmitted when fire button is pressed:
fireevent = FireEvent()


## to select the game mode
def setGameMode(gamemode, motor_controller, rgb, laser, buzzer):
        if gamemode == "virus":
            print("Virus mode")
            return VirusGame(motor_controller, rgb, laser, buzzer)
        elif gamemode == "disco":
            print("Disco mode")
            return DiscoGame(motor_controller, rgb, laser, buzzer)
        elif gamemode == "hungry":
            print("Disco mode")
            # Return Hungry game impl
        elif gamemode == "wtf":
            print("WTF mode")
            return WTFGame(motor_controller, rgb, laser, buzzer)
        else:
            print("Default mode")
            return DriveGame(motor_controller, rgb, laser, buzzer)
    
def initializeGame(gamemode):
    global hitevent
    global laser
    global buzzer
    global fireevent
    
    # reset HitEvent to remove previous subscribers
    hitevent.reset()
    fireevent.reset()
    
    # get the game
    game = setGameMode(gamemode, motor_controller, rgb, laser, buzzer)

    # setup game
    game.setup()

    ## Set the method to be called when hitevent fires!
    hitevent.subscribe(game.onHit)
    fireevent.subscribe(game.onFire)



### Gets photoresistor value over and over again
### in an infinite loop sleeping a bit to yield
### control to other tasks.
### Calls "been_hit()" when photo_resistor_value exceeds the 
### photoresistor_hit_value
async def read_photo_resistor():
    global photoresistor_value 
    global hitevent
    # Keep track of when last hit
    hit_debounce_counter = utime.ticks_ms()
    print("reading photo res")
    while True:
        photoresistor_value = photoresistor.read_u16()
        if(photoresistor_value > photoresistor_hit_value):
            print("Got hit, photores value:" + str(photoresistor_value))
            current_time = utime.ticks_ms()
            # Calculate time passed since last hit
            time_passed = utime.ticks_diff(current_time,hit_debounce_counter)
            if (time_passed > HIT_DEBOUNCE_TIME):
                hitevent.fire()
                # Save time we were last hit
                hit_debounce_counter = utime.ticks_ms()
            else:
                print("no fire event because of debounce")
        
        await asyncio.sleep(0.01)  # Yield control to other tasks

### Set baseline for photores
def calibratePhotoRes():
    global photoresistor_baseline_value
    global saved_sensitivity
    # Get current value as a baseline
    photoresistor_baseline_value = photoresistor.read_u16()
    # set the sensitivity which sets the hit level
    setPhotoResSensitivity(saved_sensitivity)
    
## Set hit factor based on sensitivity value
def setPhotoResSensitivity(sensitivity_value):
    global saved_sensitivity
    # current calibrated baseline
    global photoresistor_baseline_value
    # current hit value
    global photoresistor_hit_value
    
    print("Setting sensitivity: Baseline photores value:" + str(photoresistor_baseline_value))
    # default hit factor to .20, 20%
    sensitivity_factor = .20
    # make sure sensitivity value is between 1 and 10
    if 1 <= sensitivity_value <= 10:
        sensitivity_factor = sensitivity_value * 0.08
    
    saved_sensitivity = sensitivity_value
    hit_factor = PHOTORES_HIT_FACTOR + sensitivity_factor
    print("hit factor:" + str(hit_factor))
    photoresistor_hit_value = photoresistor_baseline_value * hit_factor
    
    print("Photores HIT value:" + str(photoresistor_hit_value))

    
    
async def execute_command(command_with_data, characteristic):
    """ Control the remote control car based on the command received """
    
    if ':' in command_with_data:
        command, command_data = command_with_data.split(':', 1)
    else:
        command = command_with_data
        command_data = ""
    
    print(f"Received command:{command}     data:{command_data}")

    if command == "move":
        move_directions = command_data.split(',')
        if len(move_directions) >= 2:
            motor_controller.move(float(move_directions[0]), float(move_directions[1]))
        else:            
            print(f"Invalid move command {move_directions}")
    elif command == "rgb":
        print(f"Setting RGB to {command_data}")
        rgb.color = tuple(map(int, command_data.split(',')))
    elif command == "stop":
        motor_controller.stop()
    elif command == "game": ## TODO: change to whatever the game mode command is
        gamemode = command_data
        print("game mode = " + str(gamemode))
        initializeGame(gamemode)
    elif command == "fire":
        print("Fire dee lazzers!!")
        fireevent.fire()
    elif command == "calibrate":
        print("Calibrate Photores!!")
        calibratePhotoRes()
    elif command == "sensitivity":
        print("Set hit sensitivity!!")
        setPhotoResSensitivity(int(command_data))
    elif command == "trim":
        print("Set Trim!!")
        motor_controller.setTrim(int(command_data))
    else:
        print("Unknown command")
        response_message = "Unknown command received."
        await characteristic.write(response_message.encode('utf-8'))
        
async def receive_data_task(characteristic):
    """ Receive data from the connected device """
    print("Waiting for commands...")
    while True:
        try:
            connection, data = await characteristic.written()
            if data:
                command = data.decode('utf-8')
                await execute_command(command, characteristic)
        except asyncio.TimeoutError:
            print("Timeout waiting for data.")
            break
        except Exception as e:
            print(f"Error receiving data: {e}")
            

async def advertise_n_wait_for_connect():
    """ Run the peripheral mode """
    # Set up the Bluetooth service and characteristic
    ble_service = aioble.Service(BLE_SVC_UUID)
    characteristic = aioble.Characteristic(
        ble_service,
        BLE_CHARACTERISTIC_UUID,
        read=True,
        notify=True,
        write=True,
        capture=True,
    )
    aioble.register_services(ble_service)

    print(f"{BLE_NAME} starting to advertise")
    global rgb
    while True:
        # advertising on, blink blue
        rgb.blink(colors=[(0, 0, 255),(0, 0, 0)])
        async with await aioble.advertise(
            BLE_ADVERTISING_INTERVAL,
            name=BLE_NAME,
            services=[BLE_SVC_UUID],
            appearance=BLE_APPEARANCE) as connection: # type: ignore
            print(f"{BLE_NAME} connected to another device: {connection.device}")
            
            # Initialize game after connected - MODIFY THIS TO THE GAME MODE YOU WANT TO LAUNCH default
            initializeGame("default")
            tasks = [
                asyncio.create_task(receive_data_task(characteristic)),
            ]
            await asyncio.gather(*tasks)
            print(f"{ROVER_NAME} disconnected")
            break

async def main():
    global rgb
    global laser
    calibratePhotoRes()

    
    # Power on, turn red
    rgb.color = (255, 0, 0)
    # stop all motor activity
    motor_controller.stop()
    
    """ Main function """
    while True:        
        tasks = [
            asyncio.create_task(advertise_n_wait_for_connect()),
            asyncio.create_task(read_photo_resistor())
        ]
        await asyncio.gather(*tasks)

print("About to execute main")
asyncio.run(main())

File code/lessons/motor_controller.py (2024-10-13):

from machine import Pin, PWM
import utime

print("Hello")
MAX_SPEED = 45000
MIN_SPEED = 5000
SLEEP_TIME_MS = 1

# Define motor pins
left_motor_forward = PWM(Pin(27))
left_motor_backward = PWM(Pin(26))
right_motor_forward = PWM(Pin(16))
right_motor_backward = PWM(Pin(17))

# Set PWM frequency
left_motor_forward.freq(1000)
left_motor_backward.freq(1000)
right_motor_forward.freq(1000)
right_motor_backward.freq(1000)

def set_motor_direction(direction, speed):
    """Set the motors' direction based on the given command."""
    if direction == 'forward':
        left_motor_forward.duty_u16(speed)
        left_motor_backward.duty_u16(0)
        right_motor_forward.duty_u16(speed)
        right_motor_backward.duty_u16(0)
    elif direction == 'backward':
        left_motor_forward.duty_u16(0)
        left_motor_backward.duty_u16(speed)
        right_motor_forward.duty_u16(0)
        right_motor_backward.duty_u16(speed)
    elif direction == 'left':
        left_motor_forward.duty_u16(speed)
        left_motor_backward.duty_u16(0)
        right_motor_forward.duty_u16(0)
        right_motor_backward.duty_u16(0)
    elif direction == 'right':
        left_motor_forward.duty_u16(0)
        left_motor_backward.duty_u16(0)
        right_motor_forward.duty_u16(speed)
        right_motor_backward.duty_u16(0)
    else:
        stop()

def stop():
    """Stop all motors."""
    print("Stopping")
    left_motor_forward.duty_u16(0)
    left_motor_backward.duty_u16(0)
    right_motor_forward.duty_u16(0)
    right_motor_backward.duty_u16(0)

def decelerate():
    for speed in range(MAX_SPEED, 0, -10):
        set_motor_direction('forward', speed)
        utime.sleep_ms(SLEEP_TIME_MS)


# Main loop to demonstrate functionality
while True:
    
    set_motor_direction('forward', 10000)
    utime.sleep_ms(3000)
    stop()

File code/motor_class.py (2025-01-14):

from machine import Pin, PWM
import utime
import math

class MotorController:
    MAX_SPEED = 65000 # Hard limit
    MIN_SPEED = 10000
    SLEEP_TIME_MS = 1
    SPIN_LOCK_TIME = 2.5

    def __init__(self):
        
        # A max speed that can be changed based on game mode or other factors
        self.max_speed = self.MAX_SPEED
        
        # Define motor pins
        self.left_motor_forward = PWM(Pin(10))
        self.left_motor_backward = PWM(Pin(11))
        self.right_motor_forward = PWM(Pin(12))
        self.right_motor_backward = PWM(Pin(13))

        # Set PWM frequency
        self.left_motor_forward.freq(1000)
        self.left_motor_backward.freq(1000)
        self.right_motor_forward.freq(1000)
        self.right_motor_backward.freq(1000)
        # Trim factor
        self.trim_factor = 0

    def setMaxSpeed(self, speed):
        self.max_speed = speed
        
    def setTrim(self, trim):
        self.trim_factor = trim

    ### x values turn and y values are for forward and reverse
    def move(self, x: float, y: float):
        """ Move the car based on x and y values """
        
        # Calculate speed based on y value
        speed = int(self.MIN_SPEED + ((abs(x) + abs(y)) * (self.max_speed - self.MIN_SPEED)))
        if speed > self.MAX_SPEED:
            speed = self.MAX_SPEED
        #print(f"Speed: {speed}")
        
        left_speed = speed
        right_speed = speed
        if y > 0 or y < 0 : # moving forward or backwards
            # calculate speed based on trim
            # decrease baseline speed by factor based on trim
            trim_adjusted_speed =  speed - (speed * (abs(self.trim_factor) * .05))
            #print(f"trim adjusted speed:{trim_adjusted_speed}")
            
            # find the difference in the speed and the trim adjusted
            speed_diff = speed - trim_adjusted_speed
            #print(f"speed diff:{speed_diff}")
            
            # add speed_diff to one or the other motor to bring that motor up to current speed
            left_speed = trim_adjusted_speed if (self.trim_factor > 0) else (trim_adjusted_speed + speed_diff)
            right_speed = trim_adjusted_speed if (self.trim_factor < 0) else (trim_adjusted_speed + speed_diff)
            left_speed = int(left_speed)
            right_speed = int(right_speed)
            #print(f"leflt speed:{left_speed}")
            #print(f"right speed:{right_speed}")

        self.left_motor_forward.duty_u16(left_speed if (x > 0 or y > 0) else 0)
        self.left_motor_backward.duty_u16(left_speed if (x < 0 or y < 0) else 0)
        self.right_motor_forward.duty_u16(right_speed if (x < 0 or y > 0) else 0)
        self.right_motor_backward.duty_u16(right_speed if (x > 0 or y < 0) else 0)
        
    ### Execute a spinning manuever and stop anything else from happening.
    def spin_lock(self):
        print("in Spin lock")
        self.stop()
        self.left_motor_forward.duty_u16(self.MAX_SPEED)
        ## Sleep the bad way to keep this thread from doing anything else
        utime.sleep(self.SPIN_LOCK_TIME)
        

    def stop(self):
        """Stop all motors."""
        self.left_motor_forward.duty_u16(0)
        self.left_motor_backward.duty_u16(0)
        self.right_motor_forward.duty_u16(0)
        self.right_motor_backward.duty_u16(0)

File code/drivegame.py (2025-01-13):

from basegame import BaseGame
from laser import Laser
from motor_class import MotorController
import asyncio

class DriveGame(BaseGame):

    ## Implement Setup
    def setup(self):
        # set color to green
        self.rgb.color = (0, 255, 0)
        self.laser.turnOff()

    ## implement on Hit.
    def onHit(self):
        print("Drive Game been hit!!")
        # Let's flash our eyes
        asyncio.create_task(self.flashRGB())
        
        
    async def flashRGB(self):
        # go red, then blue back and forth
        for x in range(5):
            self.rgb.color = (255, 0, 0)
            await asyncio.sleep(.25)
            self.rgb.color = (0, 0, 255)
            await asyncio.sleep(.25)
        
    ## Implement on Fire
    def onFire(self):
        ## Turn on laser for 5 seconds
        self.laser.fire(5)
        ## Play a beep sound
        self.buzzer.buzzTimeNFreq(.25,50)
    

    

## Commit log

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2024-10-13 added direction buttons to html and move commands to pico server code
2024-10-13 updated html to have larger buttons and better placement
2024-10-13 clean up PwmMotorTest code to be more descriptive
2024-10-13 more clean up PwmMotorTest code to be more descriptive
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2024-10-13 minor fix in motor_class.py around MIN_SPEED not having self
    [motor_class.py]
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2024-10-14 fixes to get motors controlled via bluetooth
    [PwmMotorTest.py, motor_class.py]
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2024-10-15 add initial overall diagram
    [overall.fzz]
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2024-10-15 fixed js to add stop button event
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2024-10-15 updates to diagram and add RGB code
    [overall.fzz]
2024-10-18 updates to add led eyes and diagram updates
    [overall.fzz]
2024-11-05 updates to motor controller lab
    [motor_controller.fzz, overall.fzz]
2024-11-05 note to add simple motor, no controller lab
2024-11-05 fix case issue with image
2024-11-05 removed mention of PWM in first motor controller lab.
2024-11-06 added diagrams, parts, and simple motor lesson
    [motor_controller.fzz, simple_motor.fzz]
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2024-11-07 updaates to start led tutorial
    [simple_led.fzz]
2024-11-07 update first LED lab,add second
    [simple_led2.fzz]
2024-11-07 update simple led lab
    [simple_led.fzz, simple_led2.fzz]
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2024-11-19 updates to code for new chassis and overal design
    [overall.fzz]
2024-12-12 update to overal diagram
    [overall.fzz]
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2024-12-15 update plate.md and add motor controler install pic
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2024-12-16 Update README.md to fix power.md link
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2024-12-18 updates to overall diagram for laser and photo res
    [overall.fzz]
2024-12-18 update led_pwm.md and remove eyes from main code
2024-12-18 adding laser and photo res to main server code
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2024-12-31 Refactor motor control logic and add rgb support
2024-12-31 update to overall to include laser. Added hit spin lock
    [overall.fzz]
2024-12-31 fixed bug in spin lock time)
    [motor_class.py]
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2025-01-02 Fixing typo in Update MotorController.md
2025-01-02 added tail assembly
    [overall.fzz]
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2025-01-03 moved wheel assembly to right after motor install
2025-01-03 clarified wire routing for motor controller hook up
2025-01-04 added laser to basegame and created game mode coding lesson
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2025-01-04 fixed misspelled log in motorcontroller
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2025-01-05 fixed typo on led
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2025-01-05 Added clarification for switch holder, new lines to separate images from paragraphs in power
2025-01-05 added TODO to insert photoresister section, fixed inconsistent whitespaces and typos
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2025-01-06 added buzzer class and updated virus and main to use it
    [buzzer.py, main.py, virusgame.py]
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2025-01-06 multiple changes to support fire button with virus game
2025-01-07 Update plate.md with correct wire lengths
2025-01-07 Update power.md with correct wire lengths
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2025-01-13 A couple edits and added forward/back links at the end of each section
2025-01-13 added debounce to hit detection and drive game hit flash is shorter
    [drivegame.py, main.py]
2025-01-13 link to code install after plate installed, update code install rover name
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2025-01-13 save hit sensitivity value and call set sensitivity on calibrate
2025-12-14 Fix missing frequencies in RGB LED mix colored lab
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2025-12-14 Remove right motor pin flipping instruction
    Removed instruction to flip pins for the right motor.
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2025-12-19 update pictures for wheels install to remove pico plate
2025-12-19 Updates for new print in place tracks. (#18)
    * adding new print in place track instructions
    * update wording for track assembly
    * typo
    * typov2
    * remove old pics
2025-12-19 Update power.md with installation note (#19)
    Added a note about wheels and tracks installation.
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2025-12-19 Update PartsList with new 3D printed components
    Added new components for 3D printed parts including Pico Plate, Rear Connector, Battery Door, Battery Door Key, Switch Holder, and Switch Extender.
2025-12-20 Update peg insertion instructions in plate.md
    Clarified instructions for inserting plastic pegs into the plate.
2025-12-29 New head instructions! (#21)
    * remove bulk images and new head instructions
    * cleaning up wiring diagrams
    * image links
    * fixed images
    * head instructions updated. new images added.
2025-12-30 Create RGB LED harness assembly guide (#23)
    * Create RGB LED harness assembly guide
    Added detailed assembly instructions for the RGB LED harness, including required parts and step-by-step guidance.
    * Merge rgb2 into rgb: merge harness instructions, add wiring table and fix links; move wiring guide in head.md
    * rgb swap
    * Convert inline rgb references to Markdown links in head.md
    * Convert backticked file references to Markdown links
    * final adjustments
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2025-12-31 Add buzzer installation guide to documentation (#24)
    Document the process of adding a buzzer to the Shark Rover, including required parts, wiring instructions, technical concepts of PWM, software installation, and troubleshooting tips.
2026-01-01 Update wiring instructions for motor controller (#25)
    Clarified motor controller orientation and wiring instructions.
2026-01-01 Correct pin count for red wire connection to Pico
2026-01-01 Remove power connection details for laser module (#26)
    Removed the power connection specification for the laser module.
2026-01-01 Revise packing list for 3D printed parts
    Updated packing list to reflect changes in parts and quantities.
2026-01-01 Add wiring reference and buzzer note to README (#29)
2026-01-08 Enhance assembly instructions with images and details
    Added images and additional wire information to the assembly instructions.
2026-01-08 Add Motor Controller section to plate.md
    Added a section for the Motor Controller with an image.
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2026-01-13 Change buzzer pin from 1 to 15 (#35)
    Per the assembly doc's instructions
    [main.py]
2026-01-14 Patch 1 (#32)
    * Correct 'Tranny' to 'Transmission' in wheels.md
    * Rename wheel_tranny.jpg to wheel_transmission.jpg
    * Rename wheels_no_tranny.jpg to wheels_no_transmission.jpg
    * Rename wheels_tranny.jpg to wheels_transmission.jpg
    * Rename wheels_tranny1.jpg to wheels_transmission1.jpg
    * Fix image references in wheels assembly guide
    Updated image file names for wheels and transmission.
2026-01-14 Update laser module connection details
    Clarified wire color coding for the laser module connections.
2026-01-14 Update assembly instructions for head attachment
    Added testing instructions for laser and RGB functionality before final assembly. fixes #33
2026-04-16 Add assembly instructions for old head unit
    Added detailed assembly instructions for the head unit, including parts list, eye installation, LED wiring, and final assembly steps.
2026-04-16 Remove detailed assembly instructions for old head components (#37)
    Removed detailed instructions on eye installation, LED wiring, and laser setup from the assembly guide.
2026-04-16 Fix image paths in head old assembly instructions
    Updated image paths for harness installation and head assembly.
2026-04-17 Update UA_hack_special_notes with assembly details
    Added assembly instructions and laser safety notice.
2026-08-22 Enhance wiring instructions with color details
    Added color information for wiring connections and clarified wire pairing instructions.
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2026-09-17 minor updates to wheels.md for testing holes in tracks
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2026-09-22 plate_chassis.md fixed bad image link
2026-10-12 Update chassis assembly instructions for clarity
    Clarified that motor wire colors may vary and do not affect functionality. Expanded instructions on motor orientation and installation.
2026-10-23 Enhance wire connection instructions for power switch
    Added instructions for securing wires on the power switch pins.
2026-10-23 Fix spelling error in power switch wiring instructions
    Corrected the spelling of 'loose' in the instructions for connecting wires to the power switch.
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2026-10-27 Update Packing List by removing Chassis items
    Removed items from the Packing List under Main Electronics.
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2026-10-28 Modify wire quantities in PackingList.md
    Updated quantities of wires in the packing list.
2026-10-28 Fix image path in buzzer.md
    Updated image path for PWM Duty Cycle Diagram.
2026-10-29 add link to new IR Receiver assembly to Readme and fix image paths
2026-10-29 Fix formatting of Pico WH and wires note
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2026-10-31 fixed image links in Led.md
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2026-10-31 add irlaser.py and update main to use it.Clean up unused refs to laser
2026-10-31 fix error when calling old calibrate functions
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
